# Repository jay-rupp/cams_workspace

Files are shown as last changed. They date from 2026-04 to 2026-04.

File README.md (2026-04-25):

# CAMS-Bot

**CArry My Stuff Bot** — a self-balancing two-wheeled follower robot designed as assistive technology for individuals with mobility impairments. CAMS-Bot autonomously follows a person and carries up to 5&nbsp;kg of cargo in residential environments.

Developed for **EECE 5552 – Assistive Robotics** at Northeastern University.

---

## Repository layout

| Path | Contents |
| --- | --- |
| `hardware/` | CAD files and hardware documentation for 3D-printed and laser-cut parts |
| `pico/` | MicroPython firmware for the Raspberry Pi Pico (real-time balance controller) |
| `src/` | ROS 2 workspace source — packages including `cams_bringup` |
| `dockerfile` | Container definition for the ROS 2 environment on the Pi 4 |
| `.gitignore` | |

---

## Hardware

- **Compute:** Raspberry Pi 4 (high-level control, ROS 2) + Raspberry Pi Pico (real-time balance loop)
- **Sensing:** OAK-D Pro camera (vision / person tracking), MPU6050 IMU (balance)
- **Actuation:** DFRobot FIT0186 12&nbsp;V DC gearmotors with quadrature encoders, L298N dual H-bridge driver
- **Wheels:** 8-inch polyurethane (Grainger 416P25)
- **Chassis:** Three+ laser-cut acrylic decks; 3D-printed PLA brackets and mounts; PETG wheel-to-motor bushings

---

## Setup

You will need:

1. **A Raspberry Pi 4** running Ubuntu with Docker installed.
2. **A Raspberry Pi Pico** flashed with the MicroPython UF2 firmware. Download the latest UF2 from the [official MicroPython site](https://micropython.org/download/RPI_PICO/) and flash it by holding the BOOTSEL button while plugging the Pico into USB, then dragging the UF2 onto the mounted drive.
3. **An Xbox controller** for teleop, paired to the Pi 4 over Bluetooth.

### 1. Clone the workspace

```bash
git clone <this-repo> ~/cams_workspace
cd ~/cams_workspace
```

### 2. Flash the Pico balance controller

Copy `pico/balance_controller.py` onto the Pico **as `main.py`** so it runs automatically on boot. The recommended workflow is VS Code with the [MicroPico](https://marketplace.visualstudio.com/items?itemName=paulober.pico-w-go) extension.

### 3. Build the Docker image

From the workspace root (where the `dockerfile` lives):

```bash
sudo docker build -t cams -f dockerfile .
```

### 4. Pair the Xbox controller

Pair the Xbox controller to the Pi 4 over Bluetooth before launching. Once paired, it will appear under `/dev/input/`.

```bash
bluetoothctl
# > scan on
# > pair <MAC>
# > trust <MAC>
# > connect <MAC>
```

---

## Running

### Launch the container

```bash
sudo docker run -it \
  --name ros-cams \
  --network host \
  --device /dev/ttyAMA3 \
  --device /dev/input \
  -v ~/cams_workspace:/workspace \
  cams
```

The flags do the following:

- `--network host` — required for ROS 2 DDS discovery
- `--device /dev/ttyAMA3` — UART link to the Pico
- `--device /dev/input` — exposes the Xbox controller to the container
- `-v ~/cams_workspace:/workspace` — mounts the ROS 2 workspace into the container

### Build and launch CAMS-Bot

Inside the container:

```bash
cd /workspace
colcon build
source install/setup.bash
ros2 launch cams_bringup cams_bot.launch.py
```

### Teleop controls

| Input | Action |
| --- | --- |
| Left stick Y | Forward / backward |
| Right stick X | Turning |

---

## Architecture

```
Xbox Controller ──BT──> Pi 4 ──ROS 2──> [joystick → cmd_vel → serial bridge]
                                                                 │
                                                          /dev/ttyAMA3
                                                                 │
                                                                 ▼
                                                              Pico
                                                          (MicroPython
                                                       balance controller:
                                                         IMU + encoders →
                                                          PID → L298N)
                                                                 │
                                                                 ▼
                                                          DC gearmotors
```

The Pi 4 handles high-level control and teleop; the Pico runs the real-time PID balance loop at ~20&nbsp;kHz PWM. Communication between them uses a USB serial protocol (`D<float>,T<float>\n` for drive/turn, `S\n` for stop).

---

## Authors

Built by Jason Rupp for EECE 5552. Vision and person-tracking pipeline maintained separately.

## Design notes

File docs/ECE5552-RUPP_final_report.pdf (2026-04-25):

# CAMS-Bot: A Self-Balancing Two-Wheeled Cargo Platform for Users with Mobility Limitations

Jason Rupp
Department of Electrical and Computer Engineering Northeastern University
Seattle, WA, USA
rupp.j@northeastern.edu

Abstract—Mobility-limited users in residential environments face a routine but high-leverage problem: transporting everyday items between rooms while their hands are needed for stability aids. Existing solutions either require the user to push the device or are sized and priced for industrial settings. This report describes CAMS-Bot, a residentially-scaled self-balancing two-wheeled cargo platform developed for the EECE 5552 Assistive Robotics course as a step toward closing this gap. The system is built around a Raspberry Pi 4 running ROS2 Jazzy in Docker for high-level control, a Raspberry Pi Pico running a cascaded PID balance controller in MicroPython at 100 Hz, an MPU6050 IMU, two 12 V DC gearmotors with quadrature encoders driving 8-inch polyurethane wheels through an L298N motor driver, and a hybrid chassis of laser-cut acrylic decks, 3D-printed PLA brackets, and PETG bushings at the wheel-motor coupling. Operator input is provided through an Xbox controller and a ROS2 teleoperation node communicating with the Pico over hardware UART. The delivered system balances reliably on residential carpet, accepts smooth teleoperated drive and turn commands, and holds the project’s headline 5 kg payload in static balance. Dynamic loaded locomotion at 5 kg fails for analyzed geometric reasons, and the originally proposed autonomous person-following capability was descoped during the project. The contribution is a working proof-of-concept platform with a fully documented controller, identified failure modes, and a concrete architectural roadmap to a deployable follow-on build.

I. INTRODUCTION
A. The assistive task and its users.

Many people who live with mobility limitations struggle to transport everyday items. For an impaired user, some transport tasks can be slow, painful, unsafe, or impossible without assistance. The assistive task addressed by this project was to build a small mobile robot that carries cargo on behalf of such a user and travels with them through a residential environment, freeing both of the user’s hands for stability aids and reducing the load they must support themselves.

B. Why the task matters.

Cargo carrying is a routine but high-leverage problem for the target population. Commercial service robots designed for cargo transport are sized and priced for warehouses and hospitals rather than apartments. A compact, low-cost, residentially scaled cargo robot that follows its user would meaningfully extend independent living, and the absence of such a device on the consumer market reflects the difficulty of building one well rather than a lack of need.

C. What makes the task technically challenging.
The technical challenge is unusually broad for a residential robot. The platform had to be small enough to maneuver around furniture, which pushed the design toward a two-wheel self-balancing form factor rather than a stable four-wheel base, and self-balancing introduces a real-time control problem on top of every other subsystem. The robot also had to carry a meaningful payload (the project targeted 5 kg, sufficient for the majority of personal cargo tasks), which interacts with the balance problem because added mass changes the chassis’s effective inertia and center of gravity. It needed to operate on common residential floor surfaces, such as carpet, hardwood, and tile, each of which presents different friction and rolling resistance that affect closed-loop stability. Finally, the long-term vision required onboard person tracking and following, which adds a perception pipeline running concurrently with a hard real-time balance loop on cost-constrained compute. Solving all of these problems simultaneously on a student budget was the core challenge of the project.
D. The system that was built.
CAMS-Bot (CArry My Stuff Bot) is a self-balancing two-wheeled cargo platform with a custom 3D-printed and laser-cut acrylic chassis, two 12 V DC gearmotors with quadrature encoders driving 8-inch polyurethane wheels through an L298N H-bridge, an MPU6050 IMU for tilt sensing, a Raspberry Pi 4 running ROS2 Jazzy for high-level control, and a Raspberry Pi Pico running a dual-loop PID balance controller. Drive commands are issued from an Xbox controller through a ROS2 teleoperation node on the Pi 4 and transmitted to the Pico over a hardware UART link. The system was originally scoped as follower bot with OAK-D Pro vision and YOLO-based person tracking. The delivered system balances reliably on carpet, accepts teleoperated drive, and successfully supports the 5 kg target payload during evaluation. The remainder of this report is organized as follows. Section 2 reviews related work. Section 3 describes the system as built. Section 4 presents the experimental evaluation, including PID tuning and load testing. Sections 5 and 6 discuss outcomes and lessons learned. Section 7 outlines limitations and future work.

II. RELATED WORK
CAMS-Bot sits at the intersection of three research areas: assistive mobile robotics for users with disabilities and mobility limitations, two-wheeled self-balancing platforms in the controls literature, and commercial autonomous cargo and human-following robots. This section reviews each area, identifies the gap CAMS-Bot targets, and positions the delivered system relative to prior work.
A. Target User and Context
The assistive function targeted by CAMS-Bot serves a large and well-documented population. The Centers for Disease Control and Prevention reports that disability affects a substantial fraction of the U.S. adult population, and mobility limitations are among the most common categories of disability [1]. National-level statistics on the use of mobility devices show that millions of Americans rely on these devices in daily life [2]. For this population, even routine in-home tasks that involve carrying objects compound an existing physical burden, as users must already manage a stability aid, a chronic condition, or both.
Within assistive robotics, the broad goal of empowering users with disabilities through robotic assistance is established in the literature. Chen et al. articulated this vision under the banner of ”robots for humanity,” demonstrating that mobile manipulation systems can extend independence for users with motor impairments [3]. More targeted work in the same space includes Balatti et al., who developed a robot-assisted navigation system for visually impaired users using adaptive impedance and path planning [4], and Deb et al., who designed and controlled an autonomous robot specifically for mobility-impaired patients [5]. Recent work by Olatunji et al. on the Stretch platform examines robotic support for older adults with combined cognitive and mobility impairments [6]. Common metrics for evaluating human-robot interaction in this space, including success rates, task completion times, and userreported workload, are reviewed by Steinfeld et al. [7] and operationalized through standard instruments such as NASA-TLX [8] and SUS variants [9].
CAMS-Bot’s contribution within this body of work is narrower than mobile manipulation or visual navigation. The platform addresses one specific assistive function, transporting cargo alongside a user, on a residentially-scaled chassis, leaving the user’s hands free for stability aids.
B. Existing Technical Approaches
Existing approaches relevant to CAMS-Bot fall into three categories: non-robotic mobility and carrying aids, commercial autonomous cargo and follower robots, and academic two-wheeled self-balancing platforms.
C. Non-robotic mobility aids.
Walkers, rollators, and wheeled shopping carts provide a small carrying surface for in-home and community cargo, but they require the user to push the device themselves. They provide no autonomy, no automatic following, and no mechanical assistance for the carrying task itself. For users whose strength does not support pushing a loaded device, or who need both hands free for a stability aid, these devices are inadequate.
D. Commercial autonomous cargo and follower robots. Commercial products in the human-following cargo category exist but are designed for industrial rather than residential contexts. The Foxtech FOLO-200, for example, is a four-wheel cargo robot rated for 100 kg payload and explicitly marketed for industrial transport and outdoor logistics [10]. Its scale, four-wheel base, and outdoor sensor stack are appropriate for warehouse and material-handling environments but not for the indoor residential use case CAMS-Bot targets, where the c hassis must navigate furniture and doorways. More broadly, commercial outdoor delivery robots have a documented record of safety problems in shared pedestrian environments. News reports from 2023 onward describe a sidewalk delivery robot that lost control and damaged residential property in East Hollywood [11], a delivery robot that repeatedly struck a man with cerebral palsy using a mobility scooter in West Hollywood [12], and a delivery robot that collided with an ambulance in Hollywood [13]. These incidents underscore that even well-funded commercial cargo robots do not yet operate safely around the very population that CAMS-Bot is intended to serve, and they motivate the design choice to keep the user as the direct operator of the platform rather than ceding control to a fully autonomous outdoor stack.
E. Academic and practical two-wheeled self-balancing robots. The two-wheeled self-balancing robot is a well-studied control problem, modeled as an inverted pendulum on a moving cart. PID, LQR, and hybrid control strategies have been evaluated extensively in the academic literature. Petcu and Andreescu compare PID and LQR controllers on a wheeled inverted pendulum and characterize the tradeoffs between the two approaches [14]. Saha et al. extend the platform with deep reinforcement learning alongside a PID baseline in their ”Epersist” framework [15]. Alongside the academic literature, practical builds in the maker community have demonstrated that competent balance is achievable with low-cost microcontroller hardware, an inexpensive MEMS IMU, encoderequipped DC gearmotors, and PID control. The CAMS-Bot balance controller is most directly informed by one such build: the widely-cited Instructables ”Arduino Based Self-Balancing Bot,” which provides a complete reference design including the cascaded PID structure (an inner tilt loop and an outer position or velocity loop), the MPU6050 IMU integration pattern, and a worked PID tuning sequence [16]. The CAMS-Bot implementation follows this template, with the following adaptations: the microcontroller is a Raspberry Pi Pico rather than an Arduino, the controller is written in MicroPython rather than the Arduino C dialect, the inner balance loop r uns at 100 Hz with the outer velocity loop running at a 10× lower rate via loop division, the motor driver is an L298N driven at approximately 20 kHz PWM, and the platform is scaled up to carry a 5 kg payload on 8-inch wheels rather than the small-form-factor demonstrator of the original build. Section 3.4 describes these adaptations and the dual-loop control architecture in detail.

III. SYSTEM DESIGN

A. Design Requirements

TABLE I
PROPOSAL REQUIREMENTS AND DELIVERY STATUS
Requirement | Status | Ref.

Functional
Carry payloads up to 5 kg while balanc- ing | Met | §4
Autonomously follow user at 0.5–1.5 m/s | Descoped | §3.4, §7
Maintain following distance of 0.5–1.0 m | Descoped | §3.4, §7
Detect and stop for obstacles in path | Descoped | §3.4, §7
No tracking device required on the user | Descoped | §3.4, §7

Usability
Manual override via gamepad controller | Met | §3.4
Fit through standard residential doorway | Met | §3.2

Safety
Cut motor output if tilt exceeds thresh- old | Partial | §3.4, §5
Stop on loss of user detection | Descoped | §3.4, §7
Cap autonomous following speed at 1.5 m/s | Descoped | §3.4, §7

The functional requirements are split between a delivered hardware-and-control layer and a descoped vision-andtracking layer. The 5 kg payload requirement, which was the headline assistive specification of the proposal, was satisfied during evaluation; the load test is described in Section
4. The remaining four functional requirements (autonomous following, distance keeping, obstacle response, and untethered tracking) all depend on the OAK-D Pro vision and DepthAI person-detection pipeline that was the responsibility of the project partner. That subsystem was not delivered, and consequently those requirements are reported as descoped rather than partial: no portion of the autonomous-following pipeline runs on the delivered system. The hardware required to support the descoped capability (the OAK-D Pro camera, its mount, and a wired connection to the Pi 4) is in place, and the Pi 4 to Pico command interface that an autonomous-following node would use is implemented and exercised by the manual-control node. Section 3.4 describes that interface, and Section 7 describes the work required to complete the autonomous-following capability. The usability requirements are met. The manual override mode operates through an Xbox controller connected to the Raspberry Pi 4, with commands forwarded to the Pico over hardware UART (Section 3.4). The chassis dimensions fit through a standard residential doorway. The safety requirements are partially met. The proposal’s first safety requirement specified an automatic motor cutoff if the tilt angle exceeds a safe threshold. As delivered, the system instead provides an operator-initiated kill switch that cuts power to the motors when pressed. This satisfies the requirement’s intent for the operator-in-the-loop case (the operator can disable the motors at any time), but it does not satisfy the original automatic-cutoff specification: a fall-class tilt event completes in well under a second, faster than an operator can be expected to react. An automatic tilt-threshold cutoff in the Pico balance loop is the natural extension and is identified as future work in Section 7. The remaining two safety requirements depend on the descoped vision subsystem. A stop-on-loss-of-detection behavior cannot exist without a detection pipeline, and a cap on autonomous following speed has no application when no autonomous mode is delivered. Both are reported as descoped rather than violated, since the conditions under which they would apply are not present in the delivered system. In the manual-control configuration, speed is governed by the operator and by the balance controller’s saturation behavior. A note on what is not in this table. The proposal did not separately list a requirement for stable balance across residential floor surfaces; balance was implicit in the functional requirements. As built, balance is reliable on carpet and adequate on smooth flooring such as hardwood and tile. This behavior is not a violation of any tabled requirement, but it is a real limitation of the delivered system and is discussed honestly in Section 4 (PID tuning) and Section 6 (lessons learned).
B. Robot Platform

CAMS-Bot is a self-balancing two-wheeled differentialdrive cargo platform. Figure 1 shows the assembled robot, and Figure 2 shows the system block diagram. The platform is built around four design choices that follow from the requirements in Section 3.1: a two-wheel inverted-pendulum form factor for residential maneuverability, 8-inch polyurethane wheels for traction on residential flooring, a split compute architecture that isolates real-time control from high-level processing, and a 12 V power bus sized for the motor and compute loads. Drivetrain. The drivetrain consists of two DFRobot FIT0186 12 V brushed DC gearmotors rated at 251 RPM, each with an integrated quadrature encoder. The motors are coupled to 8-inch polyurethane wheels through custom 3D-printed PETG hub adapters, described in Section 3.3. Polyurethane was selected for the wheel material because it provides higher friction on hardwood and tile than rubber-tread alternatives at the same wheel diameter, while remaining quiet on hard surfaces. The motors are driven by an L298N dual H-bridge motor driver. The L298N replaced an earlier TB6612FNG selection during integration after the TB6612FNG produced reliability problems under load; the L298N tolerated the stall and start-up currents of the 12 V gearmotors more robustly. Both motor channels are driven with PWM at approximately 20 kHz, which sits above the audible range and produces smoother current delivery to the motor inductance than lower switching frequencies.

Sensing. Tilt sensing for the balance loop is provided by an MPU6050 inertial measurement unit, which integrates a three-axis accelerometer and a three-axis gyroscope on a single I

2C device. The MPU6050 is mounted rigidly to the chassis with its sensitive axis aligned to the chassis pitch axis. Tilt angle is estimated by a complementary filter that fuses the gyroscope rate (good for short-term dynamics, prone to long-term drift) with the accelerometer-derived angle (good for long-term reference, sensitive to lateral acceleration noise). Wheel motion is sensed by the integrated quadrature encoders on each gearmotor; the Pico decodes the encoder edges in software to obtain wheel velocity for the outer velocity loop. Compute. The compute stack is split across two boards with deliberately separated responsibilities. A Raspberry Pi Pico runs the real-time balance control loop at 100 Hz. The Pico reads the IMU, decodes the encoders, runs the cascaded PID controller, and writes PWM commands to the L298N. A Raspberry Pi 4 hosts the high-level stack: Ubuntu, ROS2 Jazzy in Docker, the Xbox-controller joystick node, the teleoperation command publisher, and the serial bridge to the Pico. The two boards communicate over a hardware UART link using a simple ASCII protocol described in Section 3.4. Splitting the stack this way isolates the deterministic balance loop from the non-deterministic timing of Linux, ROS2, and any future perception pipeline.
Vision hardware. An OAK-D Pro depth camera is mounted at the top of the chassis on a custom 3D-printed mount. The camera connects to the Raspberry Pi 4 over USB. As discussed in Section 3.1, no vision software is integrated in the delivered system; the camera and its mount are present so that the planned DepthAI and YOLO-based person-tracking pipeline could be added without further mechanical or hardware work. User input and emergency stop. An Xbox controller is the user’s primary input device, connected to the Raspberry Pi 4 over bluetooth. Drive and turn commands are mapped from the controller’s analog sticks (left-stick Y for forward and back, right-stick X for turning) and forwarded over UART to the Pico. The platform also has a hardware kill switch that cuts power to the motors when pressed, providing the operator with an immediate physical override. The kill switch is the safety mechanism described in Section 3.1; an automatic tilt-threshold cutoff in the balance controller is identified as future work in Section 7.
Power. The platform uses a split power architecture. A 12 V DC battery feeds the L298N motor driver and supplies both motor channels. The Raspberry Pi 4 and the Raspberry Pi Pico are powered separately from a USB battery pack (Anker), which provides a regulated 5 V logic supply that is electrically isolated from the motor bus on the high side. The motor encoders are powered from the L298N’s onboard 5 V regulator output, so encoder logic levels are referenced to the motorside ground. Logic and motor grounds are tied together at a single point so that the Pico’s encoder inputs and PWM outputs share a common reference with the motor driver. Separating the logic and motor supplies in this way prevents motor inrush and stall currents from sagging the Pi 4’s rail and crashing the high-level stack, which is a known failure mode when both subsystems share a single battery.
Form factor. The chassis dimensions allow the robot to pass through a standard residential doorway. The cargo platform is integrated into the upper body of the chassis above the wheel axle and is sized to carry the 5 kg target payload.

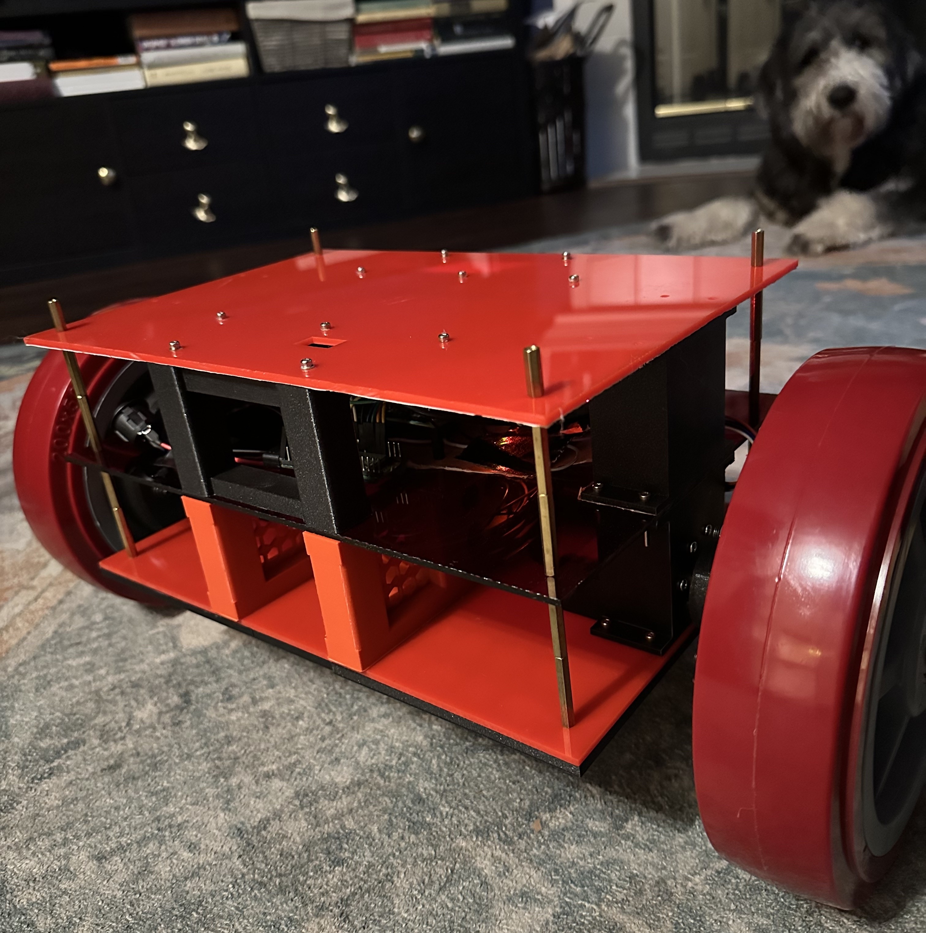
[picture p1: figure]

Fig. 1. CAMS-Bot, as built.

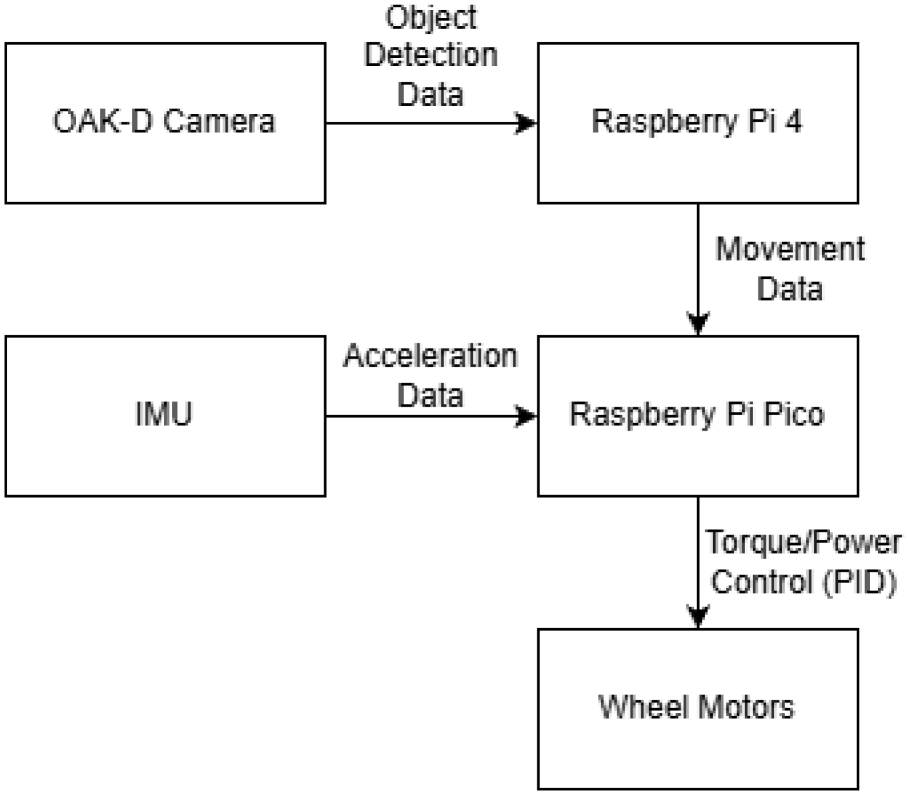
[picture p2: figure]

Fig. 2. System block diagram. The Pi 4 hosts ROS2 and the joystick teleoperation node; the Pico hosts the real-time balance and velocity loops. The OAK-D Pro and a vision-pipeline placeholder are shown for completeness; no vision software is integrated in the delivered system.

Every custom-fabricated part on the robot was designed in

CAD by the author and produced in-house at the Northeastern FlexLab maker space. The chassis is a hybrid build that uses three distinct fabrication processes and three materials, each chosen for the specific structural role it plays. Three or more laser-cut acrylic decks form the flat structural levels of the chassis; PLA-printed brackets and mounts attach the motors, battery, camera, and supports to those decks; and PETG-printed bushings couple the motor shafts to the wheels at the single highest-load mechanical interface on the robot. Twelve custom parts were designed and produced for the platform across these three categories. CAD files for all custom parts are included in the project repository.
Laser-cut acrylic decks. The chassis is built around three horizontal acrylic decks stacked vertically and joined by metal standoffs. The decks carry the electronics (motor driver, Pico, wiring, battery) on the lower levels and the cargo platform on the upper level. Acrylic was selected for the decks because the deck geometry is essentially two-dimensional: large flat panels with regular hole patterns for component mounting and standoff connections. Laser cutting produces this geometry in a single pass with tight tolerances and smooth edges, and acrylic is dimensionally stable enough that the standoff hole patterns line up reliably across all decks for clean stacking. PLA-printed brackets and mounts. The bracketry that attaches components to the acrylic decks is 3D-printed in PLA. This includes the FIT0186 motor mounts, the OAK-D Pro camera mount, the Anker battery holder for the logic-side power pack, the 12 V motor battery holder, and the structural supports that brace the deck stack against bending. PLA was the default printer feedstock available in the FlexLab and was the right choice for these parts: the brackets carry static or low-cycle loads (holding components in place against gravity and occasional handling) rather t han the repeated high-cycle loads at the wheel-motor interface, and PLA’s stiffness and dimensional accuracy serve the mounting role well. PETG-printed wheel bushings. The single highest mechanical demand on the robot is the wheel hub bushing, which couples each motor’s flatted D-shaft to the round bore of the 8-inch polyurethane wheel. Every newton-meter of motor torque is transmitted through this part, and it sees repeated impact loads from the wheel-ground contact during balancing, driving, and disturbance recovery. The bushings (Bush_v2.stl) were therefore printed in PETG rather than PLA, because PETG offers materially better toughness and creep resistance under cyclic and impact loading than PLA. PETG was scarce in the FlexLab inventory and was obtained for these parts by request to the lab staff; reserving it for the bushings, where its mechanical advantage actually matters, was a deliberate allocation given the limited supply. The bushings were also the most-iterated mechanical part on the robot. Several print revisions were required to converge on a fit that gripped the motor’s flatted shaft tightly enough not to slip under torque, while remaining loose enough to install and remove without damaging the wheel.
Design rationale and fabrication constraints. The hybrid construction reflects a deliberate match between fabrication processes and the loads each part carries: laser-cut acrylic for flat structural geometry, 3D-printed PLA for shaped lowload bracketry, and 3D-printed PETG only at the single mechanical interface where its toughness was needed. The chassis dimensions were further constrained by the working envelopes of the available equipment in the FlexLab: the laser cutter’s bed sets an upper bound on deck dimensions, and the 3D printer’s build volume sets an upper bound on the size of any single printed part. The latter constraint forced several mechanical functions to be split across multiple printed parts rather than designed as unified brackets. Producing all custom parts in-house from CAD also kept iteration cost low.

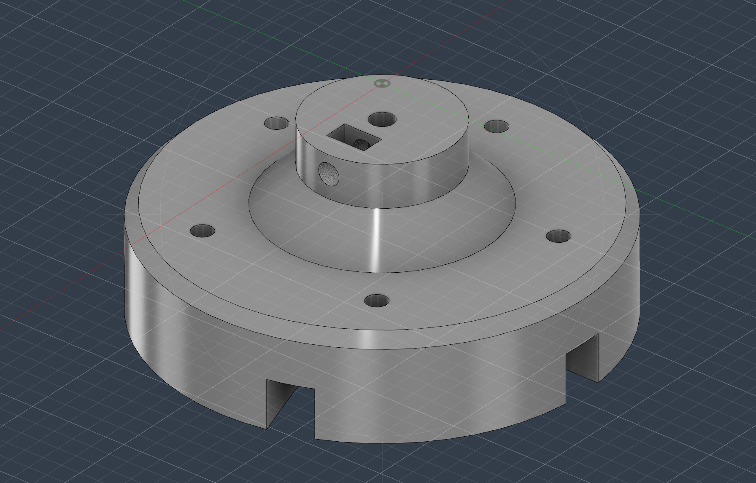
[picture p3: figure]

Fig. 3. CAD render of the PETG-printed wheel bushing (Bush_v2.stl), which couples the FIT0186 motor’s flatted D-shaft to the 8-inch polyurethane wheel. This is the single highest-load custom part on the robot.

C. Software Architecture

The CAMS-Bot software stack is split across the two compute boards described in Section 3.2, with the split chosen to isolate the deterministic real-time balance loop from the non-deterministic timing of Linux, ROS2, and any future perception pipeline. Figure 4 shows the block diagram of the delivered stack. The Raspberry Pi 4 hosts the high-level layer (Ubuntu, ROS2 Jazzy in Docker, the joystick teleoperation node, and the serial bridge to the Pico). The Raspberry Pi Pico hosts the low-level layer (the MicroPython balance controller, encoder decoding, and the L298N motor driver interface). The two boards communicate over a hardware UART link with a small ASCII protocol described below.
High-level layer (Raspberry Pi 4). The Pi 4 runs Ubuntu with ROS2 Jazzy hosted inside a Docker container. Containerizing the ROS2 environment isolates the project’s dependencies from the host system and makes the high-level stack reproducible: the same Docker image can be rebuilt on a fresh Pi 4 image with no manual ROS2 installation. Two ROS2 nodes are deployed in the container. The joystick node reads input from an Xbox controller connected over USB using pygame and publishes the controller state to the standard ROS2 /joy topic. The teleoperation node subscribes to /joy, maps the controller’s left-stick Y axis to a normalized

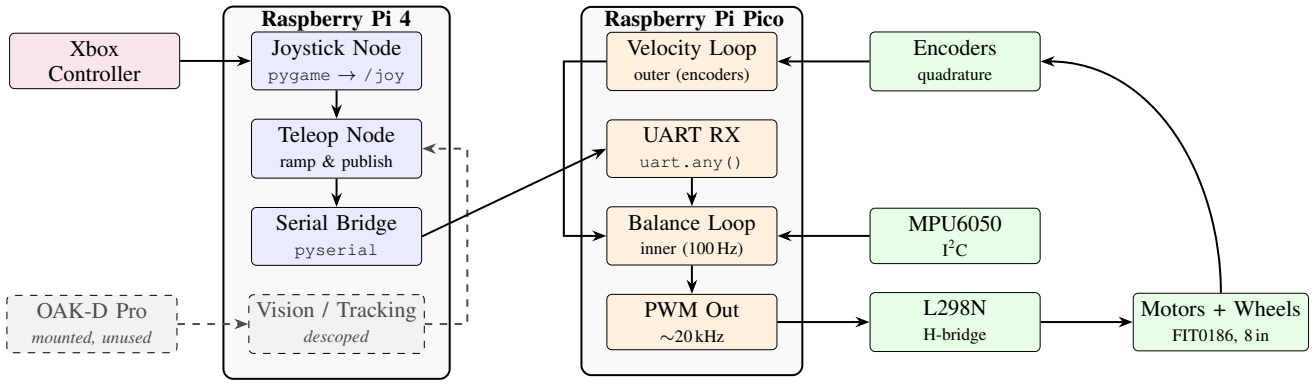
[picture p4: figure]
Raspberry Pi 4; Raspberry Pi Pico; Joystick Node; pygame → /joy; Teleop Node; ramp & publish; Serial Bridge; pyserial; Vision / Tracking; descoped; UART RX; uart.any(); Velocity Loop; outer (encoders); Balance Loop; inner (100 Hz); PWM Out; ∼20 kHz; Encoders; quadrature; MPU6050; H-bridge; Motors + Wheels; FIT0186, 8 in; Xbox Controller; OAK-D Pro; mounted, unused

Fig. 4. Software architecture and signal flow. The Raspberry Pi 4 (left, blue) runs ROS2 Jazzy in Docker with a joystick node, a teleoperation node, and a serial bridge. The Raspberry Pi Pico (center, orange) runs the cascaded PID controller in MicroPython: an outer velocity loop biases the inner balance loop’s tilt setpoint, and the inner loop drives the L298N motor driver at ∼20 kHz PWM. Hardware peripherals are shown in green. The OAK-D Pro camera and vision/tracking node (dashed) are physically present but were descoped from the delivered system.

drive command and the right-stick X axis to a normalized
turn command, ramps the commanded values at 20 Hz inside
a timer callback to avoid step changes that would shock the balance loop, and writes the resulting commands to the Pico over a serial port using pyserial.
The serial port is exposed as a stable symlink /dev/ttyPICO via a udev rule keyed on the Pico’s USB vendor ID (2e8a). This rule guarantees that the device path does not change across reboots or USB re-enumerations, which removes a class of bugs where the teleoperation node would attach to the wrong device after a hot-plug. Low-level layer (Raspberry Pi Pico). The Pico runs the real-time balance controller in MicroPython at a 100 Hz inner-loop rate. On each loop iteration the Pico (i) reads the MPU6050 IMU over I²C, (ii) estimates the chassis tilt angle from the accelerometer and gyroscope using a complementary filter, (iii) reads the wheel encoders to estimate wheel velocity, (iv) runs the cascaded PID controller described in the next paragraph, and (v) writes PWM commands to the L298N motor driver. The PWM frequency to the L298N is approximately 20 kHz, which sits above the audible range and produces smoother current delivery to the gearmotor inductance than lower switching frequencies.
Control: cascaded PID architecture. Balance and motion are produced by a cascaded two-loop controller. The inner balance loop runs every control tick and regulates chassis tilt: it produces a motor PWM command from the tilt error (measured tilt minus commanded tilt setpoint) and the tilt rate, through a PID controller with proportional, derivative, and small integral terms. The derivative term is filtered through an exponential moving average to suppress gyroscope noise, and the integral term is clamped to prevent windup during disturbances. The outer velocity loop runs at a lower rate, divided down from the inner-loop rate by an integer factor (VEL_LOOP_DIV). It compares the wheel-velocity estimate from the encoders against the commanded drive value from the high-level layer and slowly biases the inner loop’s tilt setpoint accordingly. This is the mechanism by which the robot translates a “drive forward” command into actual motion: the velocity loop deliberately leans the chassis in the desired direction, and the balance loop drives the wheels to keep up. A separate turn channel adds and subtracts a differential PWM bias to the two motor commands to produce yaw motion. The specific gain values and tuning history are reported in Section 4.
User interface. The user interface is a wired Xbox controller connected to the Pi 4 over USB. The left stick Y axis controls forward and reverse drive; the right stick X axis controls turning. Drive and turn inputs are normalized to the range [−1, 1] on the Pi 4 side and transmitted to the Pico in the ASCII protocol described next. A graphical or voice interface was not in scope.
Communication: Pi 4 to Pico ASCII protocol. The two boards communicate over a hardware UART link with a deliberately simple line-oriented ASCII protocol. Drive and turn commands are sent as D<float>,T<float>\n, where D is the normalized drive value and T is the normalized turn value, both in [−1, 1]. An immediate stop is sent as S\n. The Pico’s UART receive uses uart.any() to check for available bytes before reading, which gives a non-blocking read pattern compatible with the 100 Hz control loop. An earlier design used USB CDC serial on the Pico’s USB device interface; this was abandoned after persistent blocking-read failures, in which readline() would block on incoming newlines, read(n) would block on byte counts, and even single-byte buffered reads were sufficient to break the control loop’s timing budget. Switching to hardware UART with uart.any()-gated reads resolved the problem cleanly. Perception (descoped). The system architecture diagram shows a dashed perception module corresponding to the OAK-D Pro depth camera and the originally planned DepthAI and YOLO-based person-tracking pipeline. As discussed in Section 3.1, this subsystem was not delivered. The camera is physically mounted on the chassis and connected over USB to the Pi 4, but no vision software is integrated, no perception nodes are present in the ROS2 graph, and no autonomous mode runs on the Pi 4. The architecture is built so that adding the perception module would not require changes to the high-level node graph beyond inserting the node itself: the teleoperation node’s command interface (the same drive and turn channel forwarded over UART) is the natural insertion point for autonomous commands.
Planning (descoped). No planner runs on the delivered system. The proposed autonomous-following behavior would have used the perception module’s person-position estimate to compute drive and turn commands directly, without a separate planning layer; that simple control law was the planning equivalent in the original design and would attach at the same insertion point as the perception module above. Freespace planning, obstacle-avoidance planning, and map-based navigation were never in scope.
Safety. The delivered safety mechanism is a hardware kill switch that cuts power to the motors when pressed, providing the operator with an immediate physical override. As discussed in Section 3.1, this satisfies the operator-in- the-loop case but does not satisfy the proposal’s automatic-tilt-cutoff requirement, since fall-class tilt events complete in well under a second. An automatic tilt-threshold cutoff in the Pico balance loop is identified as future work in Section 7.
Changes from the proposal. Five elements of the software architecture changed between the proposal and the delivered system. (1) The motor driver was changed from the TB6612FNG specified in the proposal to the L298N, after the TB6612FNG produced reliability problems under the load conditions of the 12 V gearmotors. (2) The Pico balance controller is implemented in MicroPython rather than the C++ originally specified, because MicroPython provided a faster iteration loop on the Pico for the tuning-heavy development style the project required. (3) The inner balance loop runs at 100 Hz rather than the 200 Hz specified in the proposal; 100 Hz proved sufficient for stable balance and was the rate at which the IMU read, encoder decode, and PID computation comfortably fit within the loop period. (4) The Pi 4 to Pico link is hardware UART rather than USB CDC, after the USB CDC implementation was found to introduce blocking-read behavior incompatible with the control loop’s timing budget.
(5) The autonomous-following capability based on the OAK-D Pro and DepthAI was descoped, as discussed at length elsewhere in this report. The first four changes are technical refinements that produced a more reliable delivered system; the fifth is a scope reduction that resulted from the project partner’s withdrawal from the course.

IV. EXPERIMENTAL EVALUATION

A. System Tasks
The CAMS-Bot proposal defined the primary assistive task as autonomously following a user while carrying a load in a residential environment, decomposed into five subtasks: person detection and acquisition, person following, load carrying under balance, obstacle response, and manual override. As discussed in Section 3, four of these five subtasks (all but load carrying and manual override) depend on the OAK-D Pro vision and DepthAI person-tracking pipeline, which was descoped from the delivered system. Evaluating the delivered system against the original five-subtask decomposition would consist mostly of reporting “not delivered” for vision-dependent rows, which is uninformative.
This section instead evaluates the delivered system against the subset of tasks that the as-built hardware and software actually perform. Three tasks are evaluated: dynamic balance, teleoperated drive and turn, and load carrying under balance. These three tasks together exercise the full delivered stack, from the Xbox controller through the Pi 4 teleoperation node, the UART link, the Pico cascaded PID controller, and the L298N motor driver to the wheels and the chassis. They are also the three tasks against which the headline assistive specification of the project (the 5 kg payload requirement) is meaningful: a balanced platform that accepts manual drive commands and holds 5 kg of cargo is what the delivered system is, and is the closest defensible approximation of the proposal’s load-carrying-under-balance subtask.
Task 1: Dynamic balance. The robot must maintain its upright pose against the natural disturbances of the chassis and surface (small irregularities in the floor, residual asymmetries between the two motor channels, wiring tug, and so on) for an extended period without operator command. This task tests the inner balance loop in isolation and is the first task the controller had to perform during PID tuning.
Task 2: Teleoperated drive and turn. The robot must respond to drive and turn commands issued from the Xbox controller through the ROS2 teleoperation node, translating those commands into forward and reverse motion and yaw rotation while continuing to balance. This task exercises both the high-level stack (joystick node, teleoperation node, UART serial bridge) and the cascaded PID controller (the outer velocity loop that biases the inner loop’s setpoint to produce drive motion, and the differential-PWM mechanism that produces yaw motion).
Task 3: Static load-bearing and loaded locomotion. The robot must perform Tasks 1 and 2 while carrying a payload on the cargo platform, up to the project’s headline 5 kg target. This task is the assistive specification of the project: a balance platform that cannot carry meaningful cargo is not useful for the assistive task in Section 1. Task 3 is decomposed into two distinct subcases, because the delivered system’s behavior differs sharply between them. The static subcase (Task 3a) requires the robot to hold the upright pose with 5 kg of cargo on the platform, without commanded motion. The dynamic subcase (Task 3b) requires the robot to perform the drive and turn behaviors of Task 2 while loaded with 5 kg. As detailed in Section 4.4, the delivered system passes Task 3a and fails Task 3b, and the failure mechanism is geometric rather than control-related: the cargo platform sits above the wheel axle, and on the current 8-inch wheels the lean required to initiate motion under the velocity loop swings the cargo’s center of mass past the contact patch before the controller can translate

the chassis forward.
The vision-dependent tasks from the proposal (person detection and acquisition, person following, and obstacle response) are not evaluated. The proposal’s metrics for these tasks (following success rate, following distance error, and obstacle stop distance) are reported as not-applicable in Section 4.4 rather than reported with degenerate values, since the conditions of measurement (an autonomous mode, a tracked user, and a perception-driven obstacle response) are not present in the delivered system.
B. Metrics

The proposal defined five quantitative metrics for system evaluation: following success rate, following distance error, balance stability under load, obstacle stop distance, and override response time. Three of the five (following success rate, following distance error, and obstacle stop distance) measure the autonomous-following behaviors that depend on the descoped vision pipeline and are not applicable to the delivered system. Section 4.4 reports those rows as “not applicable” rather than zero, since their conditions of measurement (an autonomous mode, a tracked user, and a perception-driven obstacle response) are not present in the delivered system. The remaining two proposal metrics, balance stability under load and override response time, apply to the delivered system but in modified form. The proposal’s balance stability metric specified zero falls per trial across three payload levels (0 kg, 2.5 kg, and 5 kg), with each trial consisting of a 10 m walked path. The delivered system was tested at the binary endpoints of this payload range (unloaded driving and static 5 kg balance) rather than across the swept payload sweep the proposal specified, for the reasons discussed in Section 4.1 and Section 4.5. The override response metric (time from controller input to motor stop) applies directly to the delivered system, since both the hardware kill switch and the S serial stop command produce an immediate motor cutoff observable to the operator.
The metrics applied in this evaluation are organized by the three tasks defined in Section 4.1.
Task 1: Dynamic balance.
- Static stability outcome. Whether the unloaded chassis maintains upright pose without operator command for the duration of a test trial. Reported as a pass/fail outcome from video evidence.
- Surface dependence. Qualitative comparison of stability on residential carpet versus smooth flooring (hardwood and tile). Reported as observed behavior.
- Tuning convergence. The PID gain values that produced acceptable balance behavior, including the proportional gain KP , the integral gain KI , the derivative gain KD, the tilt setpoint, the deadband, and the minimum effective PWM. Reported as the final tuned configuration.
Task 2: Teleoperated drive and turn.
- Command responsiveness. The qualitative responsiveness of the chassis to drive and turn commands from the Xbox controller, including any observed latency or non-linearity between input and motion. Reported from video evidence.
- Override response. The behavior of the kill switch and the S serial stop command. Reported as observed cutoff behavior.
Task 3a: Static load-bearing.
- Static load capacity. The maximum payload the chassis and balance controller hold in static upright pose without falling. Reported as the binary outcome of the static 5 kg test (pass/fail).
Task 3b: Loaded locomotion.
- Dynamic load capacity. Whether the chassis can perform Task 2 (drive and turn) while loaded with 5 kg. Reported as the binary outcome of the loaded-driving test (pass/fail).
A note on quantitative versus qualitative reporting. The metrics defined here are largely qualitative or binary, rather than the continuous quantitative measures the proposal specified. This reflects two practical realities of the delivered evaluation. First, the descoped autonomous mode removes the only context in which several of the proposal’s continuous metrics (following distance error, obstacle stop distance, following success rate over many trials) would have been meaningful. Second, the project’s instrumentation and timeline did not include logged tilt-angle traces, encoder-velocity traces, or other continuous signals that would have permitted RMSerror or bandwidth reporting of the kind that fully quantifies a balance controller. The value of automated logging for future builds of this kind of system is revisited in Section 5 (Lessons Learned).
C. Experimental Procedure
The experimental work on CAMS-Bot was hand-tuning of the cascaded PID balance controller, followed by integration testing of the teleoperation stack and the load test. This section documents the procedure in enough detail for reproducibility on a similar build.
Setup conditions. Tuning was conducted indoors on residential carpet, which is the surface on which the controller behaves most reliably (Section 4.4). The robot was powered from the split power architecture described in Section 3.2 (12 V battery for the motors, USB battery pack for the Pi 4 and Pico). The Xbox controller was paired to the Pi 4 by USB. The MicroPython balance controller was edited and flashed using the MicroPico extension in VSCode, and a serial monitor on the same workstation provided real-time access to the Pico’s print output during tuning. A toggle bound to the keypress p over the serial monitor enabled the Pico to print the tilt angle and gyroscope rate at 10 Hz while balancing, which was the primary diagnostic signal during gain selection.
Pre-tuning checks. Before any controller gain was set, three pre-conditions were verified on each session, because each had been the cause of an earlier debugging session that wasted time and is documented here so that future builds do not repeat them. (i) The MPU6050 boot sequence was given a

2 s startup delay in software before the first I²C read, since shorter delays produced intermittent boot failures of the IMU. (ii) The IMU sign convention was verified empirically by tilting the chassis forward by hand and confirming the sign of the reported angle (forward tilt produces a negative value in the firmware’s convention), since a sign error in the IMU reading inverts the controller and produces an immediate fall. (iii) A motor-deadband feedforward was added to compensate for the gearmotors’ nonzero electrical start threshold. The DFRobot FIT0186 gearmotors do not begin to rotate below approximately 1 V at the motor terminals, so PWM commands below this threshold produce no motion regardless of polarity, and the closed loop is effectively open in that range. Rather than apply a simple floor (which an earlier version of the firmware tried, and which produced visible oscillation at the deadband boundary because of the discontinuous PWM step), the delivered firmware holds the motor fully off below an absolute PID output of MIN_CMD = 100 and linearly ramps a feedforward offset from zero up to MOTOR_OFFSET = 30000 between MIN_CMD and TRANSITION = 2800, with sign preserved. This produces a smooth zero-crossing at the motor’s start threshold and ensures that any controller correction the loop wants to issue is actually executed.
Tuning sequence. The PID tuning proceeded in the following order, which is the order recommended by the Instructables reference build [16] and is the order that converged in practice:
1) KP alone (pure-P loop). With KI = KD = 0, KP was increased from a small value upward until the controller produced a visible corrective response when the chassis was deflected by hand. The diagnostic for “KP is in the right neighborhood” is that the chassis fights small disturbances and tries to return to vertical, but overshoots in the form of low-frequency oscillation around the upright pose. A trial with this configuration ends when the chassis falls, when the operator stops the trial via the kill switch, or when the chassis settles into oscillation. This step also doubled as a sanity check on the IMU sign convention and the motor wiring polarity: a controller that drives the chassis further from vertical when deflected is sign-inverted somewhere, and was caught at this step rather than later.
2) Add KD. With KP fixed near its single-gain limit, KD was increased from zero until the low-frequency oscillation from Step 1 was visibly damped. The diagnostic for “KD is in the right neighborhood” is that small hand-applied disturbances are caught early in the tilt and corrected smoothly, rather than letting the tilt grow into the regime where KP produces an aggressive correction. The derivative term was filtered through an exponential moving average on the tilt rate, because raw gyroscope noise without filtering produced high-frequency motor chatter at large KD values. A trial at this step ends on a fall, a kill-switch stop, or an extended period of quiet upright balance.
3) Adjust the tilt setpoint. A persistent slow drift in one direction during otherwise quiet balance is a sign that the commanded tilt setpoint does not match the chassis’s physical balance point. The setpoint was adjusted by small increments (on the order of 0.1 deg) until the drift disappeared. The setpoint was tuned before KI rather than relying on KI to correct the steady-state offset, because integral action on a wrong setpoint produces windup rather than convergence.
4) Add KI (small). With the setpoint correctly placed, KI was increased from zero in small steps. The integral term was clamped to a finite range to prevent windup during disturbances, and was zeroed when the controller entered the deadband (defined below). For most of the development cycle KI remained at zero, since the correctly-placed setpoint plus the P and D terms produced acceptable steady-state behavior; the integral gain was used only when a small persistent offset reappeared after mechanical changes to the chassis (the addition of the camera mount, for example, shifted the balance point by enough to require either a setpoint retune or a small integral correction).
5) Engage the velocity loop. With the inner balance loop stable, the outer velocity loop was engaged. The velocity loop reads wheel velocity from the encoders, compares it against the commanded drive value from the Pi 4, and biases the inner loop’s tilt setpoint accordingly. The velocity-loop divisor (VEL_LOOP_DIV) was set so that the velocity loop runs at one-tenth the inner-loop rate, since a velocity loop that runs as fast as the balance loop produces inner-outer interaction (the velocity loop reacts to the balance loop’s transients) rather than treating the inner loop as a settled plant. Velocity-loop gains were small relative to the balance-loop gains, since their job is to bias rather than dominate the setpoint.

Deadband behavior. A small deadband was applied around the tilt setpoint inside which the controller output was zero, to prevent the controller from chattering the motors against the natural noise floor of the IMU and the encoders while the chassis was already approximately upright. A subtle bug surfaced during tuning and is documented here: the deadband must not reset the previous-error and filtered-derivative state to zero on entry. Resetting those values caused a derivative spike on each deadband re-entry, which produced visible motor twitches at the deadband boundary and degraded overall balance. The corrected behavior preserves prev_error and filtered_d across deadband transitions; the deadband only zeroes the output, not the controller’s internal state.
Trial structure. A balance trial began with the operator holding the chassis upright by hand, releasing it once the controller appeared to engage, and observing the chassis behavior until one of three terminating conditions was reached:
- Fall: the chassis tilted past the operator’s recoverable angle (approximately 30◦
from vertical) and was caught by hand or by the floor. The kill switch was used in this case to cut motor power before contact with the floor

when possible.
- Operator stop: the operator pressed the kill switch in response to oscillation, drift, or any unsafe behavior, ending the trial without a fall.
- Success: the chassis maintained upright pose, with motion confined to small natural disturbances of the surface and the wiring, for a duration sufficient to demonstrate stable balance.
A new trial began either by editing the controller gains in the firmware and re-flashing the Pico (for tuning iterations), or by simply restarting the controller with the same gains (for repeat trials of a converged configuration).
Teleoperation and load tests. Once the balance controller was tuned, the Xbox controller and the ROS2 teleoperation node were brought up on the Pi 4, and Task 2 (drive and turn) was tested by issuing drive and turn commands while the chassis balanced. The load tests for Task 3 used a known mass placed on the cargo platform: a successful Task 3a trial held the chassis upright with the 5 kg payload for the duration of a video-recorded clip; a Task 3b trial issued small drive commands under the loaded condition and was terminated by the resulting fall (Section 4.4).
Reproducibility. The MicroPython firmware, the ROS2 nodes, the udev rule for /dev/ttyPICO, and the CAD files for all custom hardware are included in the project repository. With access to the same hardware bill of materials, a reasonable-fidelity reproduction of the delivered system should be achievable in a single semester. The hard-won lessons that saved the most debugging time, listed in priority order, are:
(i) set MIN_PWM above the motor’s electrical start threshold; (ii) delay the first IMU read by 2 s after Pico boot; (iii) filter the derivative term and clamp the integral term; (iv) preserve controller state across deadband transitions; and (v) tune the setpoint before introducing KI . These items are revisited as recommendations for future teams in Section 5.
D. Results
Table II reports the outcomes of the metrics defined in Section 4.2, organized by the three tasks from Section 4.1. Quantitative values are reported where they were measured; qualitative or binary outcomes are reported where the metric was qualitative or binary by design. The remainder of the section expands on the entries that require more than a one-cell summary.
Tuning convergence (Task 1). The PID tuning sequence described in Section 4.3 converged to the gain set reported in Table III. These are the values that were live in the firmware during the video-documented balance and load tests, and constitute the controller configuration that produced the Task 1 and Task 3a passes.
Surface dependence (Task 1). The controller is tuned for, and behaves most reliably on, residential carpet. On smooth flooring such as hardwood and tile the same controller produces visibly less stable behavior: small disturbances that the carpet case rejects without operator intervention can grow on smooth flooring into oscillations large enough to require

TABLE II
RESULTS BY TASK AND METRIC
Metric | Outcome

Task 1: Dynamic balance
Static stability outcome | Pass on carpet
Surface dependence | Reliable on carpet; degraded on hardwood/tile
Tuning convergence | Final gains in Table III

Task 2: Teleoperated drive and turn
Command responsiveness | Pass; smooth response to drive and turn
Override response | Pass; immediate motor cutoff on kill switch and S stop

Task 3a: Static load-bearing
Static load capacity | Pass at 5 kg

Task 3b: Loaded locomotion
Dynamic load capacity | Fail at 5 kg (geometric tipping; see below)

Descoped (vision-dependent)
Following success rate | Not applicable
Following distance error | Not applicable
Obstacle stop distance | Not applicable

a kill-switch stop. Two contributing causes are likely. First, carpet adds rolling resistance that passively damps small velocity excursions before the velocity loop reacts to them, while smooth flooring offers no such damping. Second, the 8-inch polyurethane wheels selected for the project are intended for smooth warehouse-style floors at much higher loads than this robot applies; their durometer and tread profile produce a small, hard contact patch on smooth flooring that gives the controller less margin than a softer or larger wheel would. The combination of the as-built wheels and the controller’s lack of any surface-adaptive behavior produces the carpet-versussmooth-floor asymmetry observed during testing.
Command responsiveness and override (Task 2). The teleoperated drive and turn behaviors performed as designed. Drive commands from the Xbox controller’s left-stick Y axis produce smooth forward and reverse motion on the chassis, with the velocity loop biasing the inner loop’s tilt setpoint to lean the chassis in the commanded direction. Turn commands from the right-stick X axis produce yaw rotation through the differential-PWM mechanism. There is no observable latency between controller input and chassis response beyond what the 20 Hz teleoperation publish rate and the 100 Hz inner loop together permit. The override response is immediate by construction: the hardware kill switch cuts power to the motors at the electrical level, and the S serial stop command is executed by the Pico on the next inner-loop iteration after the byte arrives over UART, both of which produce a motor cutoff faster than an operator can perceive a delay.
Static load-bearing at 5 kg (Task 3a). The chassis, decks, motor mounts, wheel bushings, and balance controller hold the bot upright with 5 kg of cargo on the platform. The controller’s

TABLE III
FINAL TUNED CONTROLLER CONFIGURATION
Parameter | Value | Notes

Inner balance loop (PID)
KP | 1000.0 | Proportional gain
KI | 0.0 | Disabled; | infrastructure
| | clamped
KD | 700.0 | EMA-filtered
(D_FILTER_ALPHA=0.3)
Tilt setpoint | −1.0
- Empirical balance point
Deadband | 0.3
- State-preserving
Integral zone | 2.0
- Engages KI inside this band
Integral clamp | ±8.0 | Anti-windup limit

Outer velocity loop (PID)
VEL_KP | 0.002 | Velocity proportional
VEL_KI | 0.0006 | Velocity integral
VEL_KD | 0.0 | Disabled
VEL_LOOP_DIV | 10 | Outer/inner rate ratio
VEL_INTEGRAL_CLAMP | ±1.5 | Anti-windup limit
VEL_MAX_OFFSET | ±2.0
- Max setpoint bias
VEL_D_FILTER | 0.08 | Derivative low-pass

Drive input shaping
MAX_DRIVE_ANGLE | 1.5
- Lean at full stick
VEL_DRIVE_SCALE | 5500 | Trigger → velocity target
TURN_SCALE | 10000 | Stick → turn differential
VEL_RAMP_RATE | 4000 | Velocity target slew
DRIVE_RAMP_RATE | 8.0 | Drive target slew
TRIGGER_EDGE | 0.2 | Stick deadzone

Stiction-overcome kick
KICK_PWM | 12000 | Initial pulse from rest
KICK_DECAY | 0.88 | Per-tick decay factor
KICK_MIN | 200 | Floor before kick disengages

Output conditioning
MAX_OUTPUT | 65535 | 16-bit Pico PWM full scale
MIN_CMD | 100 | Below this |u|, motor fully off
MOTOR_OFFSET | 30000 | Deadband feedforward (full)
TRANSITION | 2800 | PID output where offset is
fully active
Output filter α | 0.3 | EMA on commanded output

IMU fusion and rates
Complementary α | 0.98 | Gyro | vs. | accelerometer
| | weight
Inner-loop rate | 100 Hz | MicroPython on Pico
PWM frequency | ∼20 kHz | L298N drive

existing gains (Table III), tuned for the unloaded chassis, are sufficient to maintain static balance under the increased mass and the raised center of gravity. This passes the project’s headline assistive specification on the static portion of the loadcarrying task.
Loaded locomotion failure (Task 3b). The 5 kg loaded locomotion case fails. The mechanism, summarized in Section 4.1 and analyzed in Section 4.5, is geometric: the cargo platform sits above the wheel axle, and on the current 8-inch wheels even a small commanded lean swings the cargo’s center of mass past the wheel’s contact patch before the velocity loop can deliver enough wheel acceleration to translate the chassis forward. Once the cargo center of mass crosses the contact patch, gravity’s moment arm exceeds what the motors can counter and the chassis tips. This failure is not addressable by gain tuning, since the lean that produces the failure is the same lean the velocity loop commands to initiate motion. Section 7 (Future Work) identifies larger-diameter wheels (in the range of 24–29 inches) and a chassis redesign that places the cargo platform closer to or below the wheel axle as the architectural changes that would address the failure.
Tuning headroom. The gain set in Table III produced acceptable balance behavior across the test trials but does not represent a maximally tight tuning. Two further refinements are visible from the test behavior. First, the controller is non-adaptive: the same gain set is applied across all surface conditions and all loaded conditions, and the surface-dependence asymmetry above and the loaded-locomotion failure each arise in part from the absence of a plant-conditioned gain schedule. A gain-scheduled controller, or an autotuning mechanism that adjusts gains in response to measured plant response, would address both. Second, the inner-loop gains were tuned by hand against visible chassis behavior rather than against a logged tilt trace; a logging-driven retune would tighten the gains by allowing overshoot, settling time, and steady-state error to be measured quantitatively rather than estimated visually. These refinements are identified as future work in Section 7.
E. Analysis and Discussion
Performance against requirements. The delivered system meets the proposal’s headline static specification (carrying 5 kg) and meets the operator-control and override requirements, but falls short of the dynamic 5 kg specification and of the autonomous-following functional set. The proposal’s payload requirement was articulated as “carry payloads up to 5 kg while maintaining balance,” which on a literal reading the static load test (Section 4.4, Task 3a) satisfies. On a more demanding reading, in which “carry” implies locomotion, the dynamic load test (Task 3b) does not satisfy the requirement. The honest verdict is partial: the structural and balance work that the static 5 kg case demands is delivered, and the architectural work the dynamic 5 kg case demands is not. The autonomous-following functional requirements (following at 0.5–1.5 m/s, distance keeping, obstacle response, untethered tracking) were descoped with the withdrawal of the project partner responsible for the vision pipeline, and the safety requirements that depend on those autonomous behaviors (stop on loss of detection, autonomous-mode speed cap) are descoped with them. The remaining safety requirement (motor cutoff on excessive tilt) was met partially: an operator-initiated kill switch is delivered, where an automatic in-loop tilt cutoff was specified.
Failure mode analysis: loaded locomotion (Task 3b). The dynamic 5 kg failure is the most significant performance gap and deserves a precise analysis. The mechanism is geometric, not control- related, and the distinction matters for how the failure is addressed. The cargo platform sits above the wheel axle by the height of the intermediate chassis decks. The velocity loop produces motion by biasing the inner balance loop’s tilt setpoint, deliberately leaning the chassis in the commanded direction so that the inner loop will drive the wheels forward to chase the lean. Under load, the cargo mounted at the top of the chassis swings forward in an arc around the wheel axle as the chassis leans. The horizontal displacement of the cargo’s center of mass for a given lean angle scales with the height of the cargo above the axle. With 5 kg of cargo on the current chassis, the lean angle that the velocity loop must command to initiate even a small commanded velocity is large enough that the cargo’s center of mass crosses outside the wheel’s contact patch before the wheel can translate the chassis forward. Once the cargo center of mass exits the contact patch, gravity acts with a moment arm the motors cannot counter, and the chassis tips before the controller can recover.
This failure cannot be addressed by gain tuning, because the lean that produces the failure is the same lean the controller commands to initiate motion. Tightening the gains would let the controller fight small leans harder, but the architecture requires the chassis to lean to move, and any commanded motion under a high cargo crosses the geometric tipping margin. The failure is therefore architectural and admits two architectural fixes (developed in Section 7): scale up the wheel diameter so that the geometric tipping envelope is larger and the lean angle needed to produce a given translational acceleration is smaller, or lower the cargo platform toward or below the wheel axle so that the moment arm of the loaded center of mass is reduced. Either fix changes the geometry of the platform; both together would address the failure most robustly.
Failure mode analysis: surface dependence (Task 1). The carpet-versus-smooth-floor asymmetry observed in Section 4.4 is a secondary failure mode of the controller in its current form. Two contributing causes were identified. The first is the absence of a plant-adaptive control mechanism: the gain set tuned on carpet is applied unchanged on hardwood and tile, where the rolling-resistance damping that the carpet contributes is absent and the controller operates with less effective damping margin. The second is the wheel selection. The 8-inch polyurethane wheels were specified for traction on smooth warehouse-style flooring at higher loads than this robot applies, and on residential smooth flooring under this robot’s load they produce a small hard contact patch with little compliance. A softer or pneumatically-tired wheel would absorb small surface irregularities and provide some natural damping that the rigid polyurethane does not.
Comparison to related work. The CAMS-Bot result is consistent with the controls literature reviewed in Section 2. The cascaded PID architecture adopted from Petcu and Andreescu [14] and the Instructables reference build [16] produced stable balance behavior on the delivered system, confirming that PID is a sufficient control strategy for the inner balance loop on a small two-wheeled platform when implemented carefully (correct sign convention, derivative filtering, integral clamping, and a properly placed setpoint). The platform-level result, however, diverges from the cargo-andfollowing platforms in Section 2 in a way that highlights the gap CAMS-Bot was attempting to close. The Foxtech FOLO-200 commercial follower [10] solves the loaded-locomotion problem by being mechanically passive: it uses four wheels on a stable base and never has to lean to move, so the geometric tipping problem CAMS-Bot encountered does not arise. The inverted-pendulum platforms in the academic literature [14],
[15] typically demonstrate balance without payload, and where payload is included it is mounted close to the wheel axle rather than on a raised cargo platform, so the geometric tipping mode at large loaded leans is rarely encountered. The CAMS-Bot delivered system sits between these regimes: it adopts the residentially- scaled two-wheel form factor of the academic platforms but attempts to carry the residentiallymeaningful payload of the commercial follower class, and the geometric mismatch between those two ambitions on the current hardware is the dominant lesson of the evaluation. Implications for a more robust build. The analyses above imply a specific set of architectural changes for a follow-on build that would address the dominant failure modes.
(i) The wheels should be larger in diameter (in the range of 24–29 inches) and should be pneumatic rather than rigid polyurethane, both to extend the geometric tipping envelope under load and to provide passive compliance on smooth flooring. (ii) The chassis should be metal rather than the laser-cut acrylic and 3D-printed PETG and PLA of the current build, since metal admits a stiffer structure at the larger scale that the bigger wheels imply, and admits a solid drive axle through the chassis that would replace the current motor-mounted-to-deck arrangement. (iii) A solid axle through the chassis would let the cargo platform be mounted closer to or below the axle rather than only above it, which is the second of the two geometric fixes for the loaded-locomotion failure. (iv) The vision and tracking subsystem, descoped from the delivered build, completes the autonomous functional set and is the natural software addition once the platform is hardware-robust enough to carry a camera through the residential environment without falling. These changes are developed as concrete future-work items in Section 7.
Encoder-based velocity feedback was instrumental. A specific positive finding of the evaluation is that the outer velocity loop, driven by quadrature-encoder feedback from the two gearmotors, was essential rather than optional for the controllable behavior the delivered system achieves. A balance-only configuration with no velocity feedback (an inner-loop-only PID against tilt) holds the chassis upright in static balance, but cannot be commanded to drive in any controlled way and tends to drift on the floor under small asymmetries between the two motor channels. Adding the outer velocity loop, in which the encoder-derived wheel velocity is compared against the commanded drive value and used to bias the inner loop’s tilt setpoint, is what produces the actual translational and rotational behavior of the chassis under operator command. The cost of this addition is the extra tuning surface that comes with a second control loop, including the loop-rate divisor (VEL_LOOP_DIV) and a small set of velocity-loop gains that interact with the inner-loop gains during transients. The benefit is qualitatively different behavior: a robot that holds itself up versus a robot that holds itself up and can be driven and turned. For a follow-on build, or for any future team starting from a balance-only Instructables-class reference, the encoder-based velocity loop is recommended as essential infrastructure and not as an optional refinement, even though it roughly doubles the controller’s tuning surface.
V. PROJECT OUTCOMES AND IMPACT

The CAMS-Bot project delivered a working self-balancing two-wheeled cargo platform that satisfies the structural and balance components of the proposal’s headline 5 kg payload specification, accepts manual operator control through a ROS2 teleoperation stack and an Xbox controller, and demonstrates the cascaded PID control architecture appropriate to the inverted-pendulum form factor. Within the scope it occupies, the delivered system is functional: it balances reliably on residential carpet, responds smoothly to drive and turn commands, holds 5 kg in static balance, and provides operator-initiated motor cutoff through both a hardware kill switch and a serial stop command. The dynamic 5 kg locomotion case is the primary unmet specification, for the geometric reasons analyzed in Section 4.5, and the autonomous-following functional set was descoped with the withdrawal of the project partner responsible for the vision pipeline.
Impact on the target user population. The delivered system is appropriately characterized as an early proof of concept rather than a deployable assistive device. In its current form, the platform demonstrates that a residentially-scaled self-balancing cargo robot can be designed, fabricated, and made to work on an all-maker-space build path, and that a cascaded PID controller running on a single low-cost microcontroller can produce stable balance behavior sufficient to support the assistive task. These are genuine prerequisites for a residential cargo-following device of the kind motivated in Section 1, and demonstrating them on a working build is a non-trivial contribution. However, several specific architectural changes (larger and pneumatic wheels, a metal chassis with a solid drive axle, a cargo platform mounted at or below the axle, and the descoped vision pipeline) are required before the platform could plausibly serve a user in a residential environment. Those changes are developed as concrete future-work items in Section 7. The short-term impact of the project is therefore confined to the proof-of-concept role: it shows that the problem is tractable on a student budget and identifies the specific architectural gaps a follow-on build would need to close. The long-term impact is contingent on those gaps being closed; if they were, the platform class CAMS-Bot demonstrates would address a real and underserved residential need (Section 2).
Differences from the original proposal. The delivered system differs from the proposal in three categories of change.

First, several technical refinements were made during implementation that produced a more reliable build than the proposal specified: the L298N motor driver replaced the TB6612FNG, the balance controller was implemented in MicroPython rather than C++, and the Pi 4-to-Pico link was moved from USB CDC serial to hardware UART. These changes are detailed in Section 3.4 and were each driven by an integration problem that surfaced during development. Second, the safety mechanism delivered (an operator-initiated kill switch) is a partial substitute for the proposal’s automatic in-loop tilt cutoff. Third, and most significantly, the autonomous-following capability based on the OAK-D Pro and DepthAI was descoped with the partner withdrawal one week before the project deadline. The hardware to support that subsystem (the camera, the camera mount, and the command interface from the high-level node graph to the balance controller) is in place; the vision software that would have driven it is not. This reduces the delivered system from the proposal’s autonomous follower to a manually-driven balance platform with the assistive payload-carrying behavior preserved.

VI. LESSONS LEARNED

Unexpected technical challenges. The dominant technical surprise of the project was how much of a self-balancing controller’s behavior depends on a small number of non-obvious low-level details. The motor’s electrical start threshold was not visible in any motor datasheet specification, and discovering that PWM commands below the start threshold produce no motion at all (silently corrupting closed-loop behavior, since the controller believes it has applied a correction the plant ignored) cost more debugging time than any single classicalcontrols insight. Similar non-obvious lessons surfaced for the IMU boot sequence (a 2 s startup delay on the MPU6050 is the difference between reliable initialization and intermittent boot failures), the deadband state preservation (zeroing the previous-error and filtered-derivative state at deadband entry causes derivative spikes on re-entry), and the choice of serial transport (USB CDC blocking-read behavior is incompatible with a tight control-loop budget; hardware UART with non-blocking reads solved it cleanly). None of these appears in introductory PID literature, and each had to be discovered the hard way. The geometric tipping behavior of the loaded chassis (Section 4.5) was also unexpected: classical balance-bot tutorials demonstrate balance on lightly-loaded chassis where the cargo geometry never becomes limiting, so the lesson that high-mounted cargo on small wheels makes locomotion under load impossible regardless of gain tuning is not in the standard learning path.
What went well, and why. Three things went well. First, the cascaded PID architecture adapted from the Instructables reference build [16] worked as advertised once the low-level details above were resolved, and the encoder-driven outer velocity loop in particular was instrumental in making the platform actually controllable rather than merely upright (Section 4.5). Second, the split power and compute architectures (12 V motor bus separate from the USB battery logic supply; the Pico handling deterministic balance separately from the Pi 4’s ROS2 stack) avoided entire classes of bug that would have cost real time to diagnose, and the foresight to build this split early in the project paid for itself many times over. Third, the all-in-house CAD-to-fabrication path through the Northeastern FlexLab maker space, with laser-cut acrylic decks, 3D-printed PLA brackets, and PETG only at the highest-load wheel bushing, kept iteration time to hours rather than days; this mattered most during the wheel-bushing convergence cycle.
Decisions that would change in a follow-on build. Three architectural decisions would change. The wheel selection (8-inch polyurethane intended for warehouse flooring) is the single most consequential limiter of the delivered system’s behavior, both for the geometric tipping failure under load (Section 4.5) and for the carpet-versus-smooth-floor stability asymmetry. Larger pneumatic wheels would address both. The chassis material (laser-cut acrylic and 3D-printed plastic) is appropriate for the scale of the current build but does not extend to the larger-wheeled platform a follow-on build would need; a metal chassis with a solid drive axle through the chassis admits both the larger scale and the option of mounting the cargo platform at or below the axle, which is the second of the two geometric fixes for the loaded-locomotion failure. Finally, the evaluation infrastructure should have included automated logging of tilt-angle and encoder-velocity traces from the start of tuning, rather than relying on visible chassis behavior; the gain set the project converged to is acceptable but is not maximally tight, and a logged-trace retune would have produced a more quantitatively defensible controller in the same wall-clock time.
Recommendations for future teams. Future student teams attempting a similar build should know that the project is feasible on a near-zero parts budget through maker-space fabrication, but several specific items will save substantial debugging time. Set the minimum effective controller output above the motor’s electrical start threshold, not a nominal small value. Delay the first IMU read by a generous margin (2 s on the MPU6050) before starting the control loop. Filter the derivative term and clamp the integral term as a matter of course, not as an optimization. Preserve controller state across deadband transitions; do not zero it. Tune the balance setpoint before introducing KI , and use the encoder-driven outer loop from the start rather than treating it as an optional refinement. Use hardware UART rather than USB CDC for the link between high-level and low-level boards. Plan the chassis geometry so that the cargo platform is at or below the wheel axle, and select wheels large enough that the geometric tipping envelope under expected loads is comfortable. Finally, log control-loop signals to file from day one of tuning; visible behavior is sufficient to converge a controller, but logged traces are sufficient to converge it well.
Personal learning. The project required learning, from a base of no prior exposure, both classical control theory at the level needed to implement and tune a cascaded PID balance controller, and parametric mechanical CAD at the level needed to design every custom part on the robot. Both domains became genuinely usable through the iterative hardware-inthe-loop work the project required, in a way that classroomonly exposure does not produce. The delivered system is a proof of concept with known and specifically-articulated limitations rather than a deployable device, but it works, and it works well enough on the static portion of its headline specification to demonstrate that the class of platform CAMS-Bot represents is achievable on a student budget by a single author with maker-space access.

VII. LIMITATIONS AND FUTURE WORK

The delivered CAMS-Bot system has well-characterized limitations, identified through the evaluation in Section 4 and the analysis in Section 4.5. This section enumerates them and pairs each with concrete future work that would address it. The items are ordered roughly by impact on the assistive task: hardware geometry first, then control and operator interface, then software completeness.
Limitation: loaded locomotion fails (Task 3b). The current 8-inch wheels and the cargo platform mounted above the wheel axle produce a geometric tipping envelope too small to admit the lean required for loaded driving (Section 4.5). Future work: a chassis redesign using larger pneumatic wheels in the 24–29 inch range, a metal frame stiff enough at that scale, and a solid drive axle through the chassis. The solid axle admits two changes that the current motor-mounted-todeck arrangement does not: a structurally robust drive coupling between motor and wheel that does not depend on a 3D-printed bushing as the load path (see weak-point limitation below), and a cargo platform mounted at or below the axle plane to reduce the moment arm of the loaded center of mass.
Limitation: the wheel-to-motor coupling is the mechanical weak point. The PETG-printed wheel bushings (Bush_v2.stl) sit between the FIT0186 motor’s flatted D-shaft and the polyurethane wheel bore, and every newton-meter of motor torque passes through this single 3D-printed part. The bushings hold under the loads the current platform applies, but they are the part most likely to fail under the higher torques a heavier loaded build would impose, and a slipping or fatigued bushing produces the worst class of failure (silent loss of drive on one wheel, with the controller continuing to issue commands the chassis can no longer execute). Future work: a solid metal axle running through the chassis, with the wheels keyed to the axle and the motors driving the axle through a belt or chain reduction. This replaces the printed bushing as the load-path element and decouples wheel mounting from motor mounting, allowing each to be optimized independently. Limitation: stability is surface-dependent. The same gain set produces reliable balance on residential carpet but degraded behavior on hardwood and tile (Section 4.4). Two contributing causes were identified: the controller is non-adaptive across surfaces, and the polyurethane wheels were specified for warehouse flooring rather than residential surfaces. Future work: pneumatic wheels would provide passive compliance on smooth flooring that the current rigid polyurethane does not, addressing the wheel-side cause. A gain-scheduled or autotuning controller that adjusts gains in response to measured plant response would address the controller-side cause; a simple version schedules gains based on a surface-detection signal (for example, the variance of the tilt rate during quiet balance), and a more sophisticated version uses the encoder-velocity loop’s tracking error to identify plant conditions online.
Limitation: flat ground only. The platform was tested on level surfaces. Inclines and thresholds were not evaluated. Although no specific failure mode on inclines has been observed, the controller is non-adaptive (above), the velocity loop’s setpoint biasing assumes a level surface as the natural balance point, and the small wheel diameter does not roll over thresholds well. Future work: the larger pneumatic wheels and gain-scheduled controller above are prerequisites for inclined or threshold operation; explicit testing across inclines, hardwood-to-carpet transitions, and small thresholds would then validate the upgraded platform on the surface distribution of an actual residence.
Limitation: throttle control through the Xbox controller is coarse. The current drive-input shaping (Sec-
tion 3.4 and the MAX_DRIVE_ANGLE, VEL_DRIVE_SCALE, VEL_RAMP_RATE, and TRIGGER_EDGE parameters) pro-
duces controllable but coarse throttle response: the analog stick maps to lean angle and velocity target without a tunable response curve, and the operator does not have fine control at low speeds. Future work: introduce a configurable response curve on the analog input (an exponent or a piecewise-linear curve) so that small stick deflections produce small velocity targets with finer resolution, while full-stick deflection still produces the maximum lean. A second improvement is operator-tunable maximum lean and maximum velocity, exposed as ROS2 parameters on the teleoperation node rather than as firmware constants on the Pico, so that the same firmware can be used across operator preferences without re-flashing.
Limitation: safety relies on operator-initiated cutoff. The delivered safety mechanism is a hardware kill switch (Section 3.1, Section 3.4), which satisfies the operator-in-the-loop case but does not satisfy the proposal’s automatic in-loop tilt cutoff for fall-class events that complete faster than an operator can react. Future work: an automatic tilt-threshold cutoff in the Pico balance loop. The implementation is small: when the absolute tilt exceeds a threshold (for example, 30◦ ),
drive PWM to zero unconditionally and require an explicit operator reset before resuming. This is straightforward to add and is a high-priority safety improvement.
Limitation: the autonomous-following capability was descoped. The OAK-D Pro and DepthAI person-tracking pipeline that the proposal specified was not delivered (Section 3.4). The hardware to support it (camera, mount, USB connection to the Pi 4, and the same drive/turn command interface used by the manual teleoperation node) is in place. Future work: a vision and tracking node that runs on the Pi 4 in ROS2, performs YOLO-based person detection on the OAK-D Pro stream, estimates the user’s bearing and range relative to the chassis, and publishes drive and turn commands to the Pico through the same UART protocol the manual teleoperation node currently uses. The descoped safety requirements (stop on loss of detection, cap on autonomous-mode speed) would be implemented alongside this node.
Limitation: evaluation was qualitative rather than logged. The metrics in Section 4.4 are largely binary or qualitative, because the project’s instrumentation did not include logged tilt-angle, encoder-velocity, or controller-output traces. Future work: log these signals to file (or stream them to the Pi 4 over UART for recording) during all subsequent tuning and evaluation. Quantitative metrics such as RMS tilt error, velocity-loop tracking error, and disturbance-rejection time become available once the signals are logged, and the gains in Table III can be tightened against measured performance rather than visual inspection.

VIII. CONCLUSION

This report described CAMS-Bot, a self-balancing two-wheeled cargo platform developed for the EECE 5552 Assistive Robotics course as a step toward a residentially-scaled cargo-following device for users with mobility limitations. The motivating assistive task is the routine but high-leverage problem of transporting everyday items between rooms, a task that compounds the existing physical burden of users who rely on stability aids. Existing solutions either require the user to push the device (rollators and walkers) or are sized and priced for industrial environments rather than residential use, leaving a gap that CAMS-Bot was designed to address.
The delivered system is built around a Raspberry Pi 4 running ROS2 Jazzy in Docker for high-level control, a Raspberry Pi Pico running a cascaded PID balance controller in MicroPython at 100 Hz, an MPU6050 IMU for tilt sensing, two 12 V DC gearmotors with quadrature encoders driving 8-inch polyurethane wheels through an L298N H-bridge, and a hybrid chassis built from laser-cut acrylic decks, 3D-printed PLA brackets, and PETG bushings at the wheel-tomotor coupling. An Xbox controller provides operator input through a ROS2 teleoperation node that forwards drive and turn commands to the Pico over a hardware UART link. The platform balances reliably on residential carpet, accepts smooth teleoperated drive and turn commands, and successfully holds the project’s headline 5 kg payload in static balance. The dynamic 5 kg locomotion case fails for analyzed geometric reasons, and the autonomous person-following capability was descoped with the withdrawal of the project partner responsible for the vision pipeline. The principal contributions of the project are a working residentially-scaled self-balancing cargo platform built on a near-zero-cost maker-space fabrication path, a fully documented cascaded PID controller including several non-obvious low-level practices (smooth deadband feedforward, state-preserving deadband, stiction-overcome kick, complementary IMU fusion) that are essential to the platform’s behavior, and a clear architectural roadmap (Section 7) for the follow-on build that would extend the platform from proof of concept to deployable assistive device.

REFERENCES

[1] Centers for Disease Control and Prevention, “Disability impacts all of us infographic,” https://www.cdc.gov/disability-and-health/articles-documents/disability-impacts-all-of-us-infographic.html, (https://www.cdc.gov/disability-and-health/articles-documents/disability-impacts-all-of-us-infographic.html) July 2024, national Center on Birth Defects and Developmental Disabilities. Accessed: 2026-03-09.
[2] Disabled World, “Mobility device statistics: United States,” https: //www.disabled-world.com/disability/statistics/mobility-stats.php, October 2022, accessed: 2026-03-09.
[3] T. L. Chen, M. Ciocarlie, S. Cousins, P. M. Grice, K. Hawkins, K. Hsiao,
C. C. Kemp, C.-H. King, D. A. Lazewatsky, A. E. Leeper et al., “Robots for humanity: using assistive robotics to empower people with disabilities,” IEEE Robotics & Automation Magazine, vol. 20, no. 1, pp. 30–39, 2013.
[4] P. Balatti, I. Ozdamar, D. Sirintuna, L. Fortini, M. Leonori, J. M. Gandarias, and A. Ajoudani, “Robot-assisted navigation for visually impaired through adaptive impedance and path planning,” 2023. [Online]. Available: https://arxiv.org/abs/2310.14705
[5] A. Deb, Z. Wypych, J. Lonner, and H. Ashrafiuon, “Design and control of an autonomous robot for mobility-impaired patients,” IFAC-PapersOnLine, 2021. [Online]. Available: https://www.sciencedirect.com/science/article/pii/S2405896321022254 (https://www.sciencedirect.com/science/article/pii/S2405896321022254)
[6] S. A. Olatunji, J. S. Shim, A. Syed, Y.-L. Tsai, A. E. Pereira, H. P. Mahajan, R. A. Mudar, and W. A. Rogers, “Robotic support for older adults with cognitive and mobility impairments,” Frontiers in Robotics and AI, 2025. [Online]. Available: https://www.frontiersin.org/journals/robotics-and-ai/articles/10.3389/frobt.2025.1545733/full (https://www.frontiersin.org/journals/robotics-and-ai/articles/10.3389/frobt.2025.1545733/full)
[7] A. Steinfeld, T. Fong, D. Kaber, M. Lewis, J. Scholtz, A. Schultz, and M. Goodrich, “Common metrics for human-robot interaction,” in Proceedings of the 1st ACM SIGCHI/SIGART conference on Human-robot interaction, 2006, pp. 33–40.
[8] S. G. Hart, “Nasa-task load index (nasa-tlx); 20 years later,” in Proceedings of the human factors and ergonomics society annual meeting, vol. 50, no. 9. Sage publications Sage CA: Los Angeles, CA, 2006, pp. 904–908.
[9] J. R. Lewis, “Measuring perceived usability: The csuq, sus, and umux,” International Journal of Human–Computer Interaction, vol. 34, no. 12, pp. 1148–1156, 2018.
[10] Foxtech, “FOLO-200 heavy duty 100kg four-wheel cargo trolley
automatic human-following cart robot,” https://store.foxtech.com/folo-200-heavy-duty-100kg-four-wheel-cargo-trolley-automatic-human-following-cart-robot/, (https://store.foxtech.com/folo-200-heavy-duty-100kg-four-wheel-cargo-trolley-automatic-human-following-cart-robot/) 2024, foxtech Store. Accessed: 2026-03-09.
[11] KTLA, “Food delivery robot goes rogue, causes property damage
at | East | Hollywood | home,” | https://ktla.com/news/local-news/
food-delivery-robot-goes-rogue-causes-property-damage-at-east-hollywood-home/, (https://ktla.com/news/local-news/food-delivery-robot-goes-rogue-causes-property-damage-at-east-hollywood-home/) 2023, kTLA 5 News. Accessed: 2026-03-09.
[12] ABC7, | “Man | with | cerebral | palsy | repeatedly | hit | by
delivery | robot | in | West | Hollywood,” | https://abc7.com/post/
delivery-robot-hits-man-cerebral-palsy-mobility-scooter-west-hollywood/ 17866465/, (https://abc7.com/post/delivery-robot-hits-man-cerebral-palsy-mobility-scooter-west-hollywood/17866465/) September 2023, accessed: 2026-03-09.
[13] FOX | 11 | Digital | Team, | “Food | delivery | robot, | ambu-
lance | collide | in | Hollywood,” | https://www.foxla.com/news/
food-delivery-robot-ambulance-collide-in-hollywood, (https://www.foxla.com/news/food-delivery-robot-ambulance-collide-in-hollywood) January 2026, fOX 11 Los Angeles. Accessed: 2026-03-09.
[14] R. Petcu and G.-D. Andreescu, “Two-wheeled inverted-pendulum self-balancing robot with LQR or PID control,” in 2022 IEEE Conference, 2022. [Online]. Available: https://ieeexplore.ieee.org/document/9922862/ (https://ieeexplore.ieee.org/document/9922862/)
[15] S. Saha et al., “Epersist: A two-wheeled self balancing robot using PID controller and deep reinforcement learning,” in 2022 IEEE 19th India Council International Conference (INDICON), 2022. [Online]. Available: https://ieeexplore.ieee.org/document/10003940/
[16] Instructables, | “Arduino | based | self-balancing | bot,” | https:
//www.instructables.com/Arduino-Based-Self-Balancing-Bot/, | 2024,
accessed: 2026-03-09.

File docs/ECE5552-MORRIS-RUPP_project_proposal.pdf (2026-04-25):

# CAMS-Bot: An Autonomous Load-Carrying Follower Robot

Timothy Morris
Department of Electrical and Computer Engineering Northeastern University
Seattle, WA, USA
morris.t@northeastern.edu

Jason Rupp
Department of Electrical and Computer Engineering Northeastern University
Seattle, WA, USA
rupp.j@northeastern.edu
I. MOTIVATION

The target population for this assistive technology is those with mobility impairments, such as those who need an assistive device to walk or a wheelchair. Mobility impairment is the most prevalent disability among U.S. adults. According to the CDC, 12.2% of U.S. adults experience serious difficulty walking or climbing stairs, and 7.7% have an independent living disability characterized by difficulty performing errands alone [1]. These two populations overlap significantly and both could benefit from assistive devices. Mobility disability is particularly common among middle-aged adults, affecting nearly one in five, and among older adults, affecting approximately one in four [1]. The consequences of limited mobility extend beyond inconvenience. Users of mobility devices face significant challenges in achieving independence; the vast majority report difficulty using public transit — for many, it is insurmountable — and a majority cannot leave their homes without encountering steps [2]. Load carrying, such as grocery shopping, is among the most routine yet physically demanding daily tasks for this population and often necessitates reliance on another person. Although autonomous follower robots are commercially available, some will be outlined later in the report, none are specifically designed as assistive technology for individuals with mobility impairments. There are numerous reports of autonomous delivery robots gone awry, causing damage to gardens [3], colliding with emergency response vehicles [4], and endangering sidewalk users [5]. This system would not only need to be aware of the user it needs to follow, but also of its surroundings. What also makes this technically challenging is that the robot’s design is self-balancing. The act of balancing will need to be adaptive to the load mass the robot is carrying. A self-balancing design may introduce some unnecessary challenges and overall load-carrying weight, but it would be more agile and able to maneuver in tight spaces with only two wheels. This prototype is targeting users in residential settings where the ability to work in confined spaces will be an advantage, even though other sacrifices will be required. CAMS-Bot is a self-balancing two-wheeled autonomous follower robot designed specifically as assistive technology for individuals with mobility impairments, autonomously carrying loads over distances. The robot can carry loads up to 5 kg and is designed to autonomously follow its user through residential environments at walking speeds of 0.5–1.5 m/s. The system uses a depth camera for person-following and obstacle avoidance, a real-time balance controller running on a dedicated microcontroller, and a single-board computer for high-level navigation and user interaction. An Xbox controller or other Bluetooth-capable device interface provides a manual override mode, ensuring the user always remains in control. By autonomously carrying loads, CAMS-Bot aims to reduce physical strain and extend the functional independence of users who would otherwise rely on a caregiver for assistance. The prototype targets indoor and residential use cases, where its compact two-wheeled form factor provides a maneuverability advantage over wider multi-wheeled platforms in confined spaces such as hallways and doorways.

II. RELATED WORK

A. Target User and Context
The target population for CAMS-Bot — individuals with mobility impairments who use assistive devices such as canes, walkers, or wheelchairs — faces a largely unaddressed gap in assistive robotics. While robotic assistance for mobility-impaired users has received growing research attention, existing systems focus predominantly on fall prevention and gait assistance rather than load carrying. Prior work, such as an autonomous fall-prevention follower robot by Vogt et al. [6], demonstrates the viability of autonomous person-following for mobility-impaired users, but focuses on physical support rather than cargo transport. Research into robot-assisted navigation for the visually impaired has explored adaptive impedance control and path planning to guide users through environments [7], yet this work similarly does not address the load-carrying need. Similarly, participatory design studies with older adults using the Stretch mobile manipulator found that item delivery and load carrying were among the most desired but underserved robotic assistance tasks [8]. These findings motivate the design of a system specifically tailored to the load-carrying need.
B. Existing Technical Approaches
The closest commercial parallel is Foxtech’s FOLO series — the FOLO-200, for example, is a heavy-duty cargo trolley with automatic human-following technology capable of carrying up to 100 kg [9]. However, this and similar products are designed for warehouses and industrial logistics, not residential environments, and not specifically for users with disabilities. They require the user to carry a dedicated handheld tracking device, are built for flat industrial floors, and are not designed around the constraints of a mobility-impaired user navigating a community or residential environment. CAMS-Bot targets this underserved space by combining person-following via a depth camera with a self-balancing two-wheeled platform optimized for confined indoor spaces, without requiring the user to wear or carry any tracking device.
On the control side, two-wheeled self-balancing robots are a well-studied platform, typically modeled as wheeled inverted pendulums. PID-based balance controllers have been widely demonstrated [10], [11], with cascaded control architectures separating the inner balance loop from the outer velocity loop being a common approach. Person-following using depth cameras has also been explored extensively, with stereo and RGB-D camera systems enabling robust target tracking in indoor environments [12]. CAMS-Bot builds on these established techniques, applying them in a novel assistive context where balance must remain stable under a variable payload — a constraint not addressed in prior self-balancing robot literature.

III. SYSTEM OVERVIEW

A. Design Requirements
Functional Requirements:
- The robot shall carry payloads up to 5 kg while maintaining balance.
- The robot shall autonomously follow its user at walking speeds of 0.5–1.5 m/s.
- The robot shall maintain a safe following distance of 0.5– 1.0 m behind the user.
- The robot shall detect and stop for obstacles in its path.
- The robot shall not require the user to wear or carry any tracking device.
Usability Requirements:
- The robot shall provide a manual override mode accessible via a Bluetooth gamepad controller, allowing the user to pause, redirect, or stop the robot at any time.
- The robot shall fit through a standard residential doorway. Safety Requirements:
- The robot shall cut motor output immediately if tilt angle exceeds a safe threshold.
- The robot shall stop immediately upon loss of user detection.
- The robot shall not exceed 1.5 m/s in autonomous following mode.
B. Robot Platform
CAMS-Bot is built on a custom 3D-printed and wood-reinforced chassis, designed to accommodate 8-inch polyurethane wheels for traction in residential environments. The drivetrain consists of two DFRobot FIT0186 12V DC

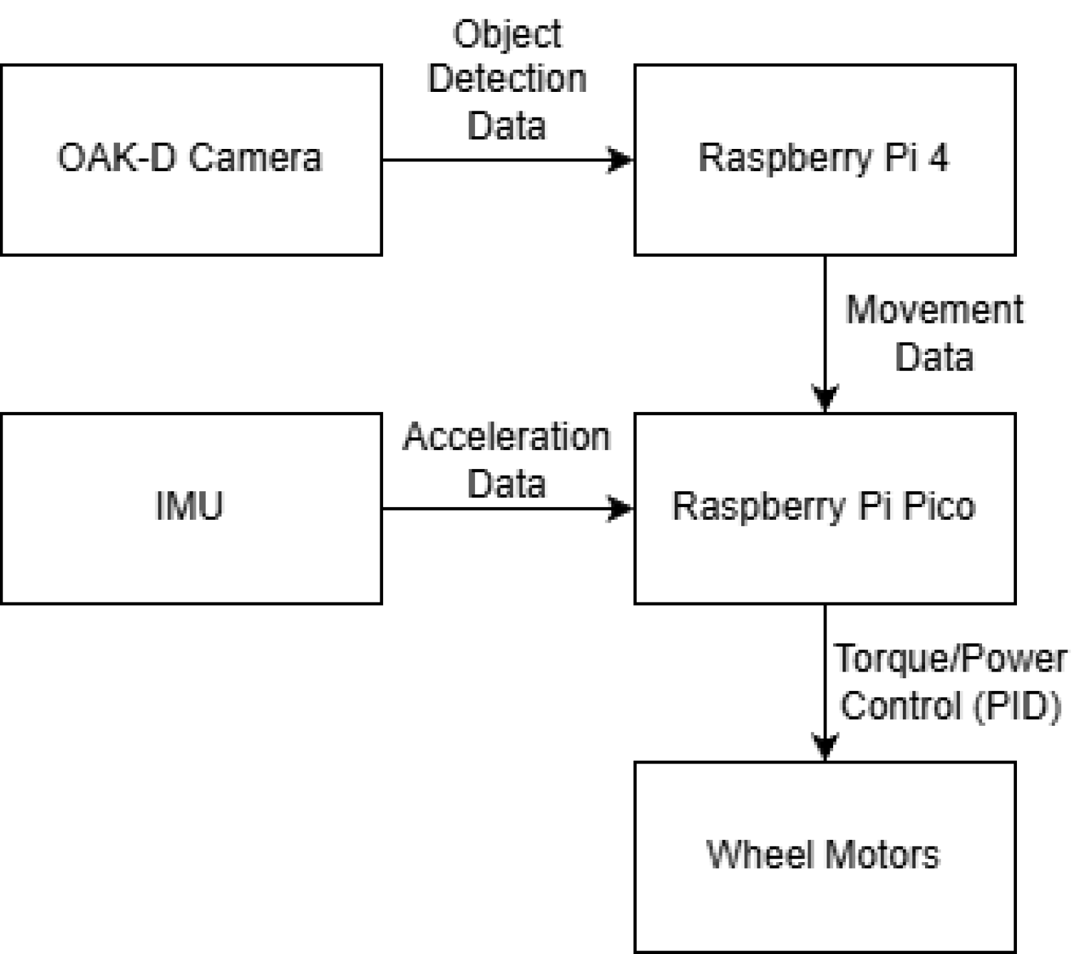
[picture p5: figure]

Fig. 1. System block diagram showing the two-layer compute architecture.
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

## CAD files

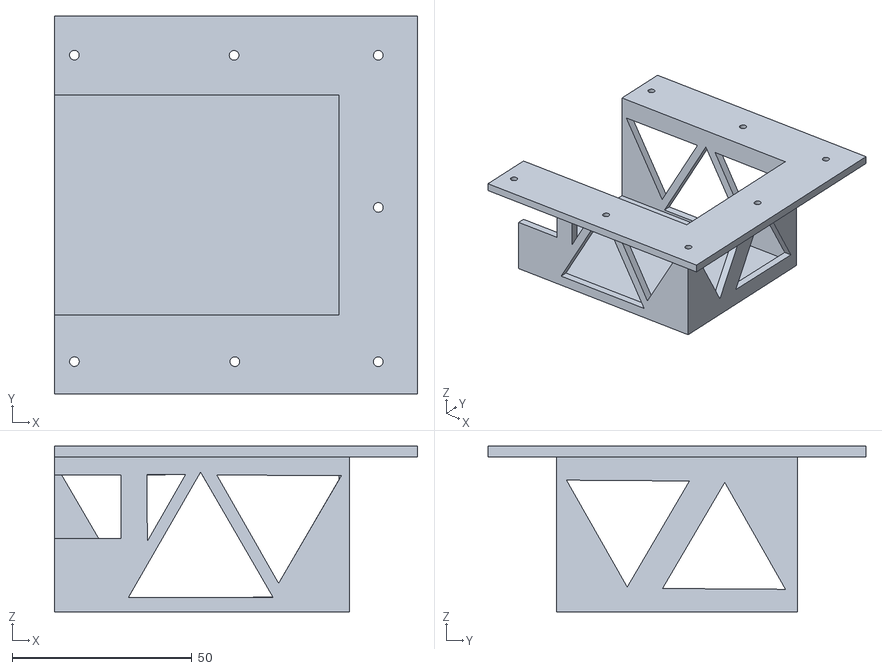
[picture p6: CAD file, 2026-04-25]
hardware/motor_battery_holder.stl
100.9 x 105.0 x 46.0

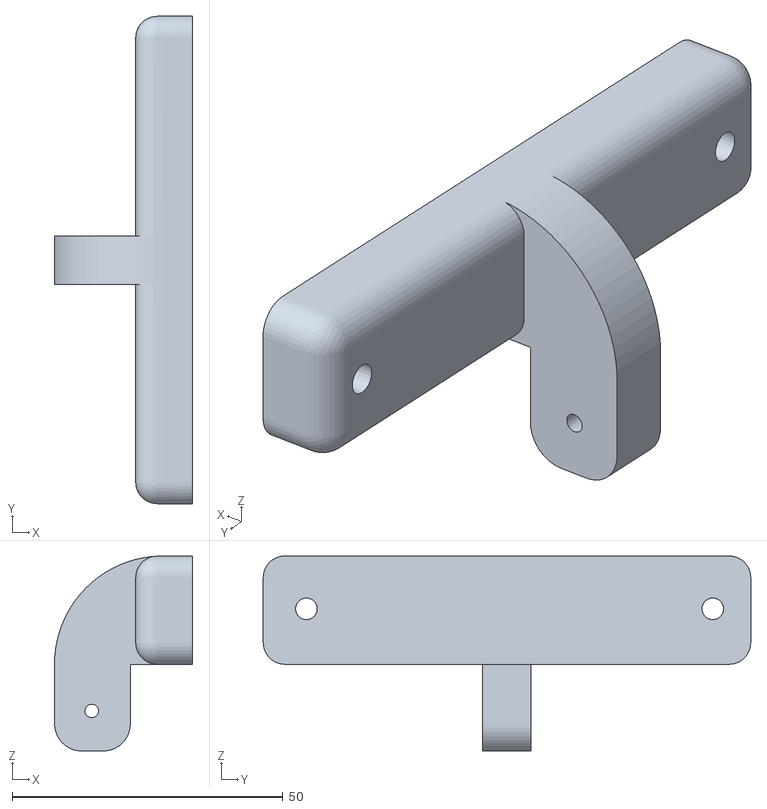
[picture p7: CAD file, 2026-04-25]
hardware/oak-d_mount.stl
25.5 x 90.0 x 36.0

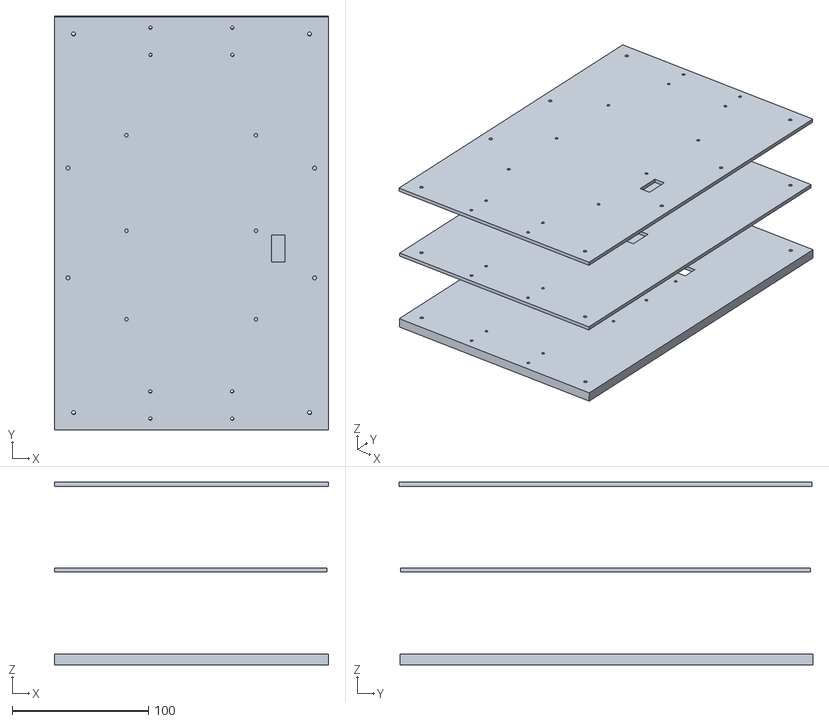
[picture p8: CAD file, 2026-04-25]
hardware/cams_redesign.stl
201.1 x 303.5 x 134.0

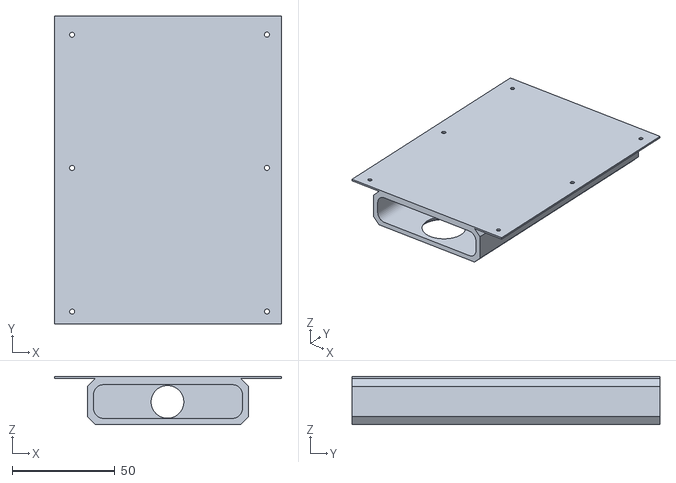
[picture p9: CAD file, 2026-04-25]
hardware/anker_battery_holder.stl
110.7 x 150.0 x 23.5

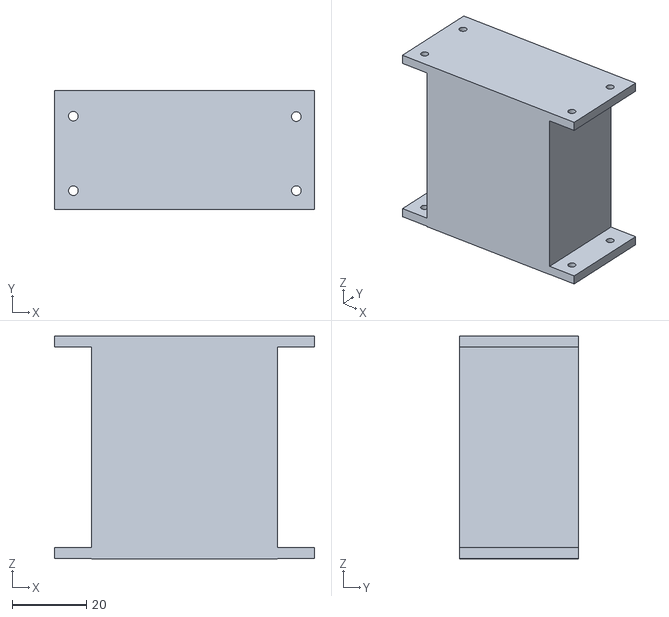
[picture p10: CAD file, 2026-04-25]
hardware/Motor_holder_dummy_BOTTOM.stl
70.0 x 32.0 x 60.0

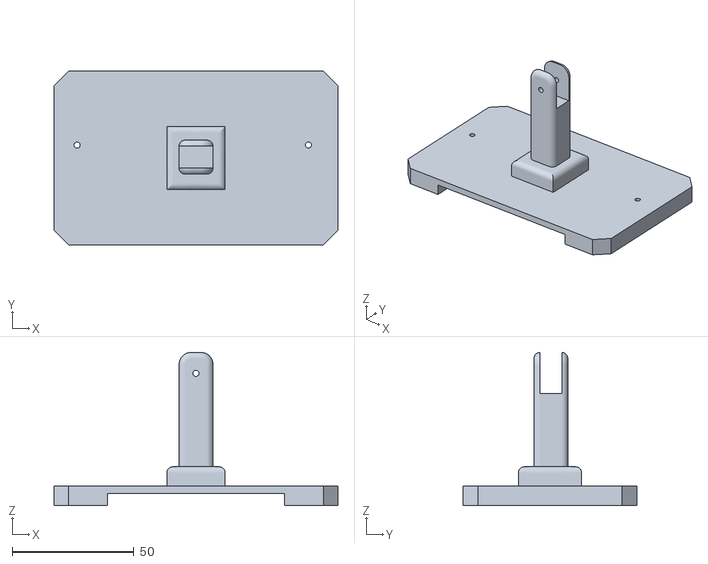
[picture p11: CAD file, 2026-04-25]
hardware/camera_mount.stl
116.8 x 71.4 x 63.0

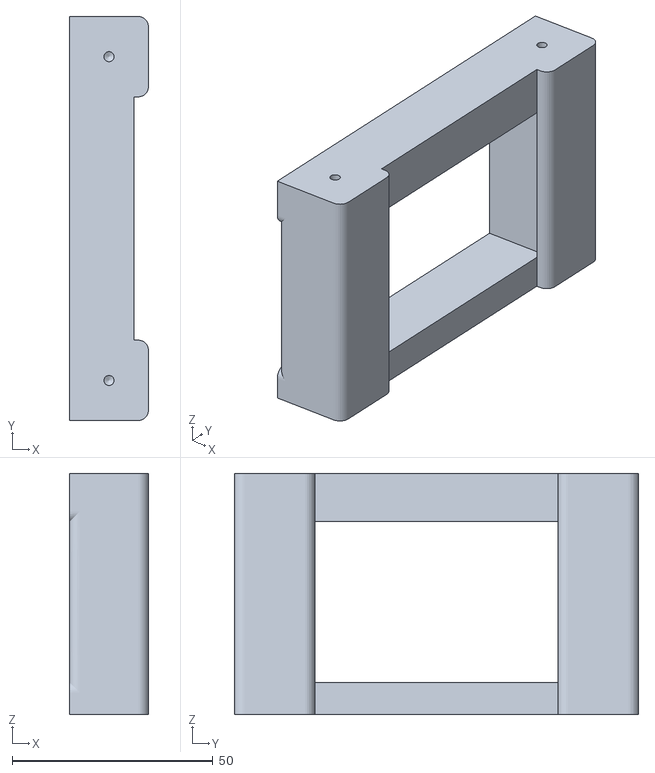
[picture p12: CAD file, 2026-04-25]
hardware/middle_support.stl
19.6 x 100.5 x 60.0

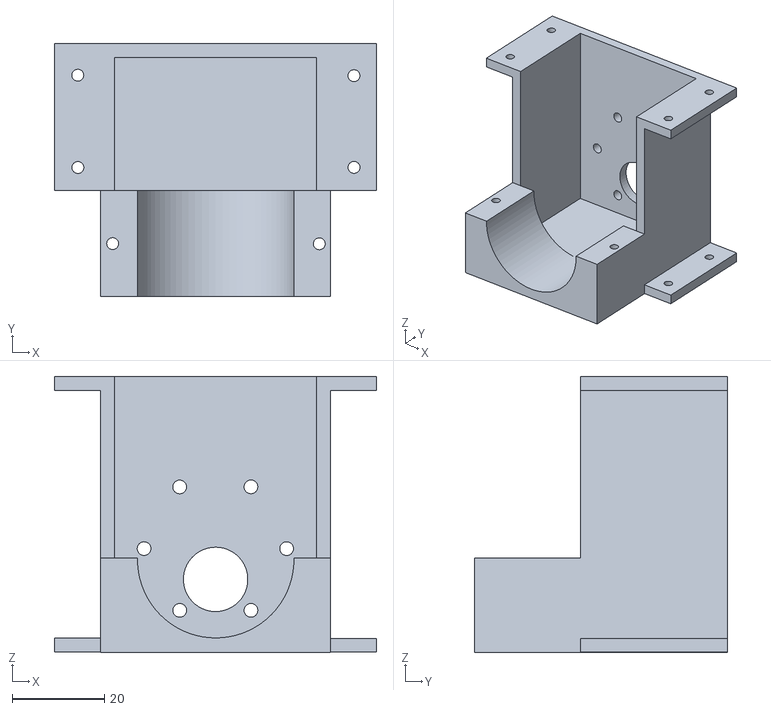
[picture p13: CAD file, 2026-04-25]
hardware/Motor_holder_FIT0186_BOTTOM.stl
70.0 x 55.0 x 60.0

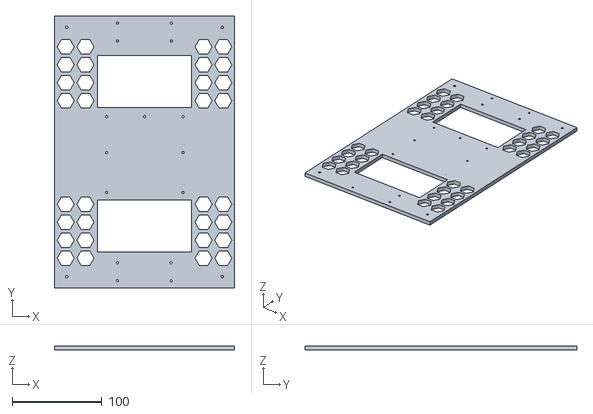
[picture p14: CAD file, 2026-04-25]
hardware/cams_redesign_support.stl
201.0 x 303.0 x 5.00

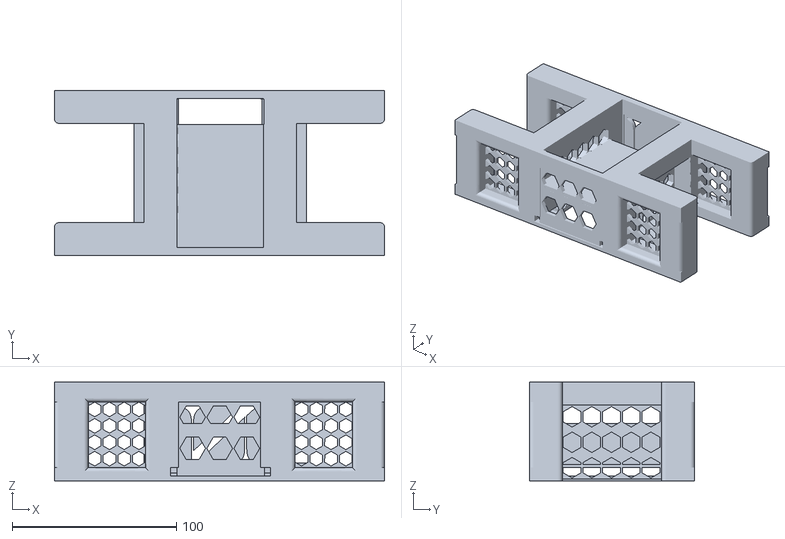
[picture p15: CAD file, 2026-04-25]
hardware/bottom_support.stl
201.0 x 100.5 x 60.0

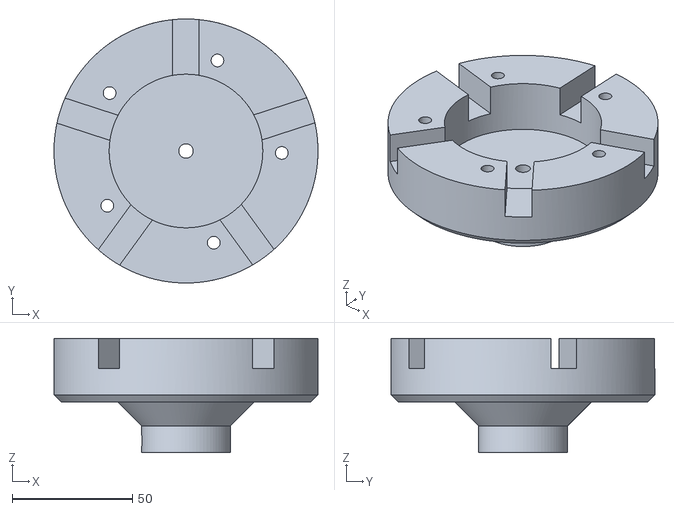
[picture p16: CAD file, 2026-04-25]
hardware/Bush_v2.stl
110.0 x 110.0 x 47.5

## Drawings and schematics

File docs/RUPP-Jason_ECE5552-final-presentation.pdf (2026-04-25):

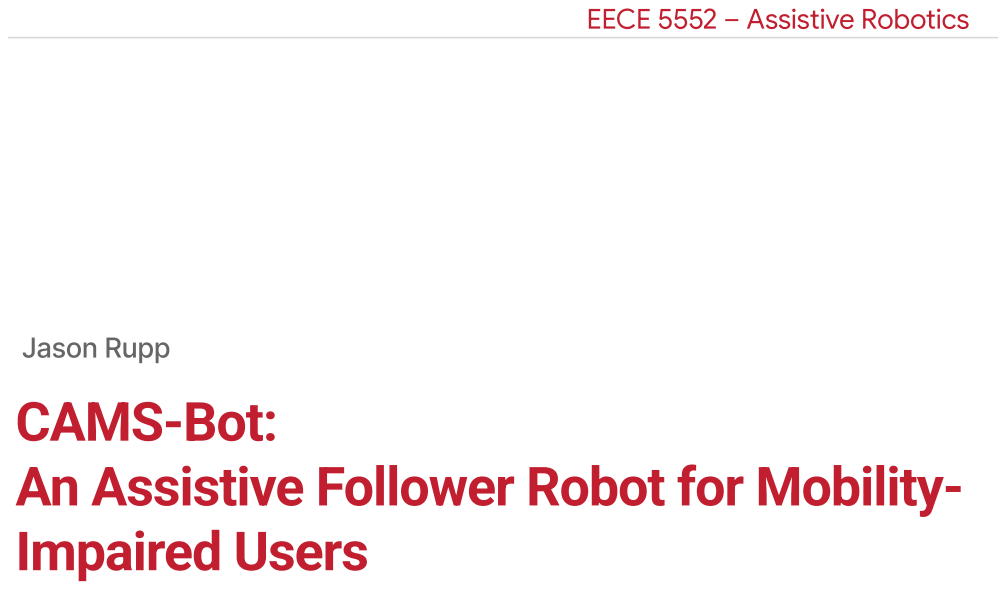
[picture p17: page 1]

Jason Rupp
CAMS-Bot:
An Assistive Follower Robot for Mobility-
Impaired Users

## Agenda

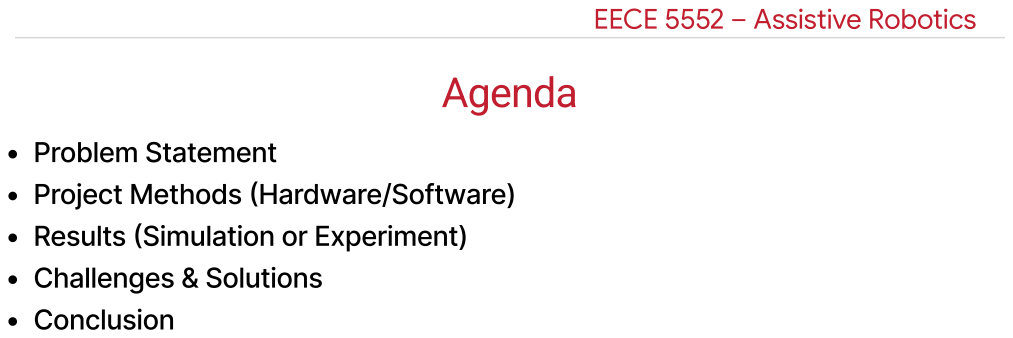
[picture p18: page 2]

Problem Statement
Project Methods (Hardware/Software)
Results (Simulation or Experiment)
Challenges & Solutions
Conclusion

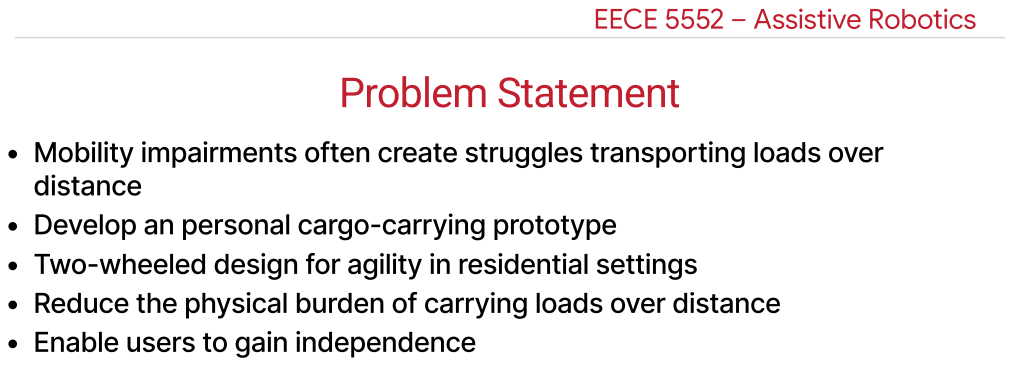
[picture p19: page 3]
Problem Statement

Mobility impairments often create struggles transporting loads over
distance
Develop an personal cargo-carrying prototype
Two-wheeled design for agility in residential settings
Reduce the physical burden of carrying loads over distance
Enable users to gain independence

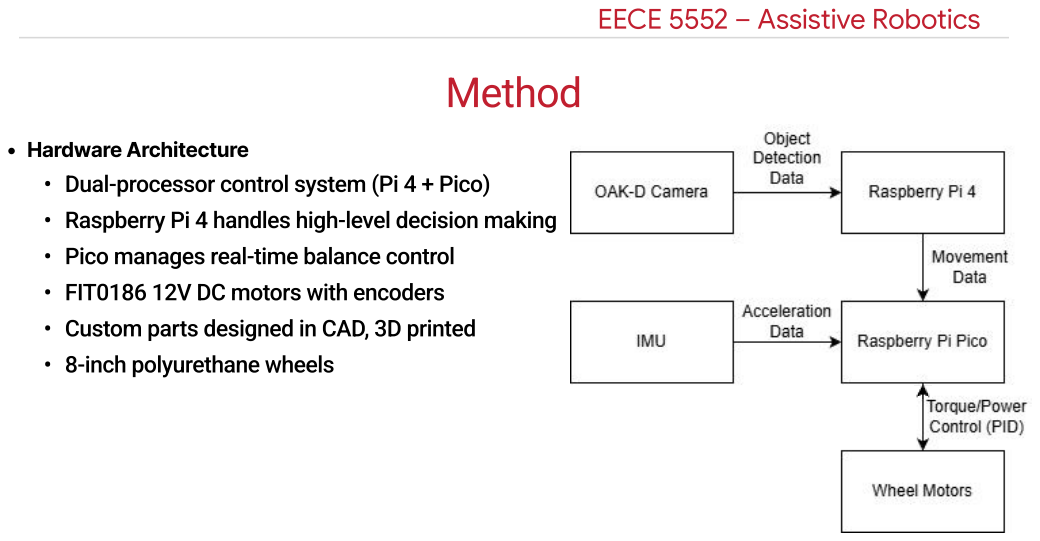
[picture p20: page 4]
Method

Hardware Architecture
Dual-processor control system (Pi 4 + Pico)

Raspberry Pi 4 handles high-level decision making

Pico manages real-time balance control

FIT0186 12V DC motors with encoders

Custom parts designed in CAD, 3D printed

8-inch polyurethane wheels

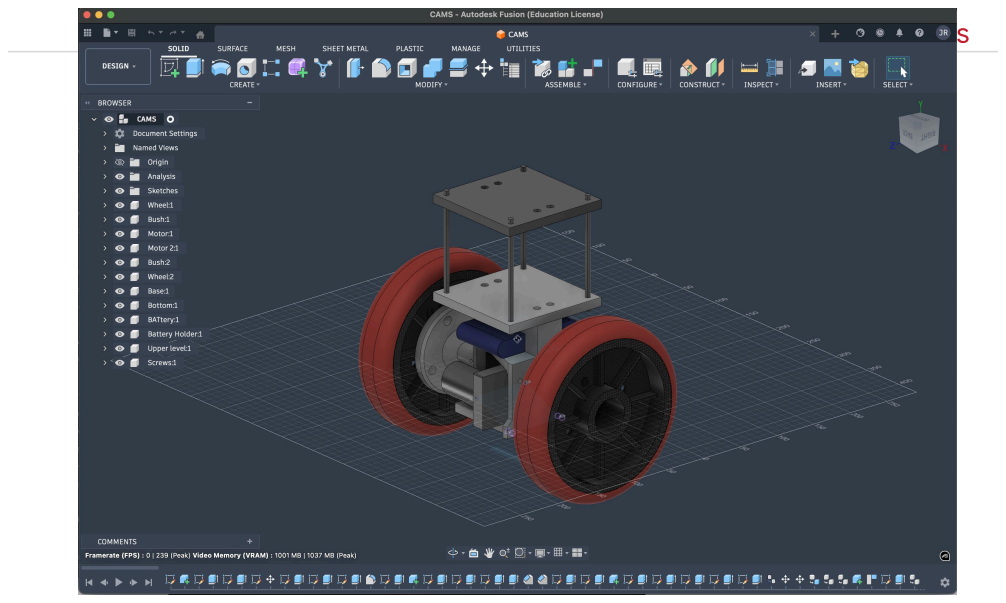
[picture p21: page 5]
Outcomes

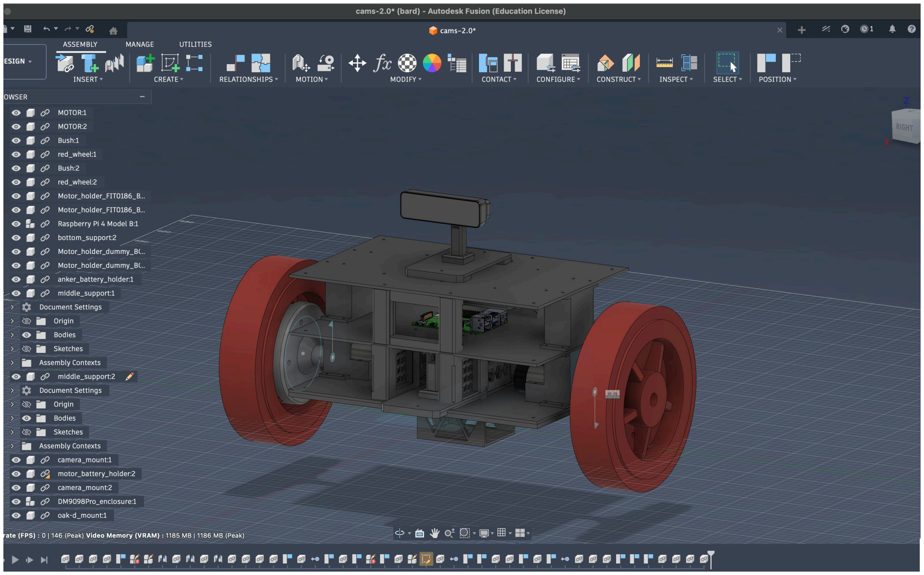
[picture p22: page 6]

## Method

Custom Made Parts

## Method

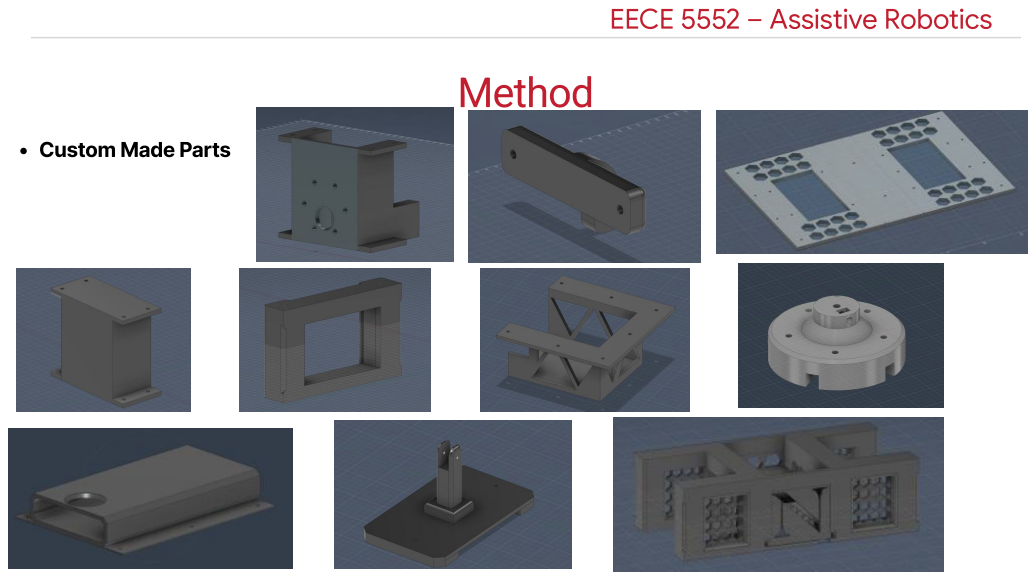
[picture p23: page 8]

Custom Made Parts

# Method

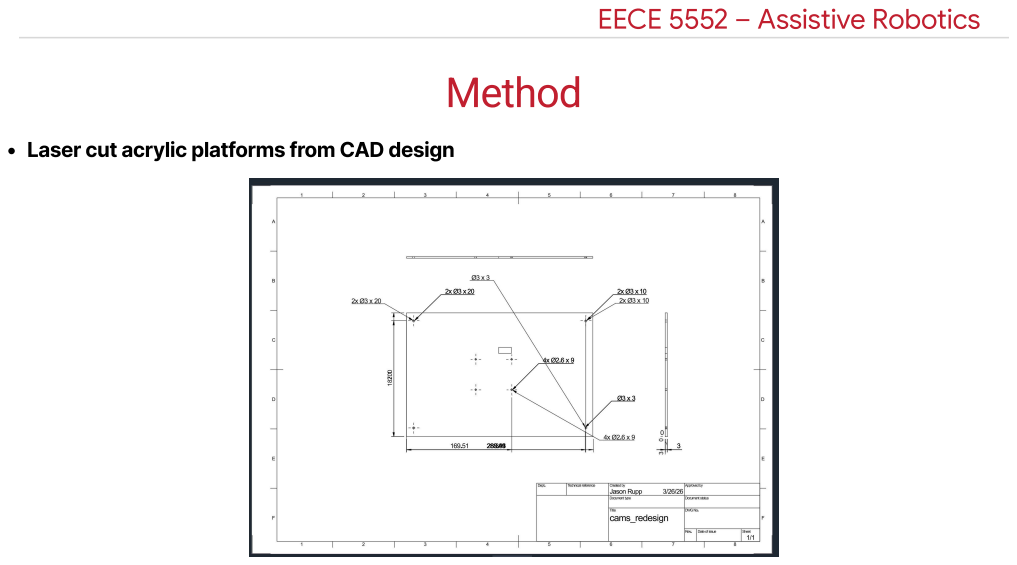
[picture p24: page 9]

Laser cut acrylic platforms from CAD design

## Method

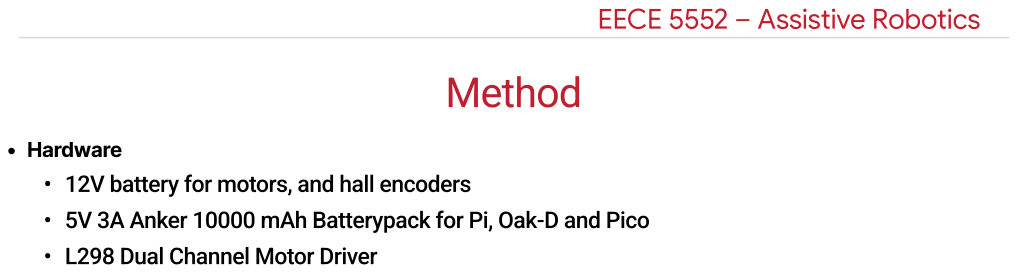
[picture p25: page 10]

Hardware
12V battery for motors, and hall encoders
5V 3A Anker 10000 mAh Batterypack for Pi, Oak-D and Pico
L298 Dual Channel Motor Driver

# Method

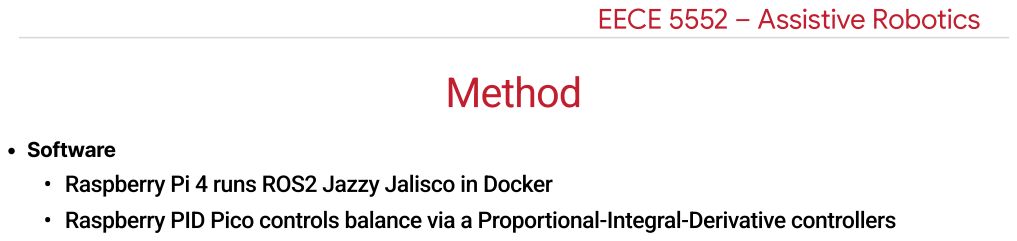
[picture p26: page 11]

Software
Raspberry Pi 4 runs ROS2 Jazzy Jalisco in Docker
Raspberry PID Pico controls balance via a Proportional-Integral-Derivative controllers

# Method

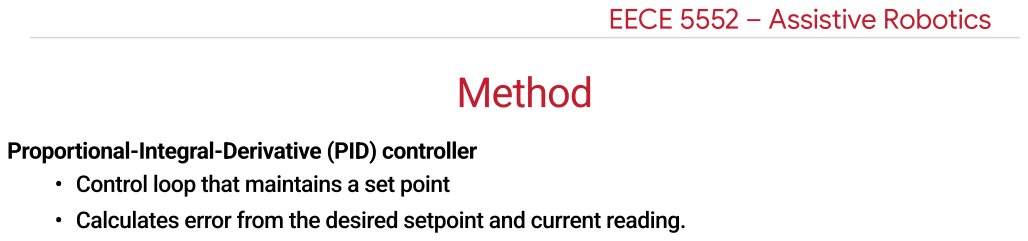
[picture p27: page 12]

Proportional-Integral-Derivative (PID) controller
Control loop that maintains a set point
Calculates error from the desired setpoint and current reading.

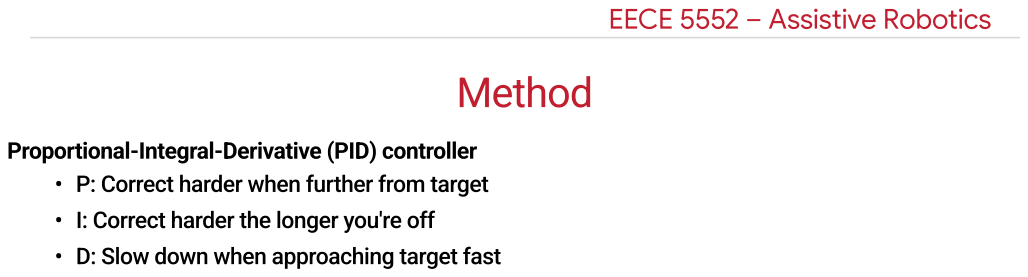
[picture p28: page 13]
Method

Proportional-Integral-Derivative (PID) controller

P: Correct harder when further from target

I: Correct harder the longer you're off

D: Slow down when approaching target fast

## Method


Proportional-Integral-Derivative (PID) controller
PID Controllers for angle (IMU) & velocity (Encoders)
PD only for lean angle - P alone oscillates — D dampens overshoot
PI only for lean angle - P alone drifts — I eliminates steady-state error

Hardware

## Live Demo

# Challenges & Solutions

# Challenges & Solutions


Conclusion

Conclusion

Conclusion

## Questions

References

https://www.cdc.gov/disability-and-health/articles-documents/disability-impacts-all-of-us-
infographic.html (https://www.cdc.gov/disability-and-health/articles-documents/disability-impacts-all-of-us-infographic.html)

https://store.foxtech.com/human-following-robot/

https://www.instructables.com/Arduino-Based-Self-Balancing-Bot/

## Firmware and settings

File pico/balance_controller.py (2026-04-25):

"""
CAMS Bot — cascaded PID balance controller
Pico MicroPython  |  MPU-6050 (I2C)  |  L298N dual H-bridge
Encoders: FIT0186 hall quadrature, 2797 ticks/rev

Wiring
------
MPU-6050
  SDA -> GP0   SCL -> GP1   VCC -> 3V3   GND -> GND

L298N  (Motor A = left, Motor B = right)
  ENA -> GP2  (PWM)   IN1 -> GP3   IN2 -> GP4
  ENB -> GP5  (PWM)   IN3 -> GP6   IN4 -> GP7

Encoders
  Left:   A -> GP12  B -> GP13   (inverted)
  Right:  A -> GP10  B -> GP11

UART1 (commands from Pi 4, 115200 baud)
  TX -> GP8   RX -> GP9

Serial commands
  D<float>,T<float>,B<float>\n  — drive, turn, boost (joystick ±1.0, trigger 0–1)
  S\n                           — stop (smooth ramp-down)
  K\n                           — kill switch: stop motors and zero state
  R\n                           — resume from kill

Drive model
  Joystick D value: lean offset for balance setpoint
  Joystick T value: differential PWM for turning
  Right trigger B value: forward throttle (sets velocity setpoint)

Motor deadband compensation (smooth)
------------------------------------
Measured: L298N + FIT0186 motors don't start spinning until ~30000 PWM
under load. Without compensation, the PID issues commands the motors
ignore until output gets large, then slams.

This file uses a SMOOTH ramp instead of an abrupt step at MIN_CMD:
- output near zero          → near-zero motor PWM (no jolt)
- output up to TRANSITION   → offset ramps linearly from 0 → MOTOR_OFFSET
- output above TRANSITION   → full MOTOR_OFFSET added

This avoids the "instant 30k step at zero crossing" that causes 10Hz
limit-cycle oscillation around the setpoint.
"""

from machine import Pin, PWM, I2C, UART
import struct, time, math

# ── Inner loop (balance) tuning ───────────────────────────────────────────────
SETPOINT       =  -1.0    # base tilt target (degrees)
KP             =  1000.0
KI             =  0.0
KD             =  700.0
LOOP_HZ        =  100
DEADBAND       =  0.3    # degrees
MAX_OUTPUT     =  65535
ALPHA          =  0.98    # complementary filter
D_FILTER_ALPHA =  0.3     # derivative low-pass
OUTPUT_FILTER  =  0.3

DT = 1.0 / LOOP_HZ

INTEGRAL_ZONE  = 2.0
INTEGRAL_CLAMP = 8.0

# ── Motor deadband feedforward (smooth) ──────────────────────────────────────
# MIN_CMD: below this absolute output value, motor is fully off (true zero)
# MOTOR_OFFSET: full offset added at and above TRANSITION
# TRANSITION: PID output value at which the offset becomes fully active.
#   Below TRANSITION, offset scales linearly from 0 → MOTOR_OFFSET.
#   This avoids an abrupt PWM step at zero-crossing that causes oscillation.
MIN_CMD        = 100
MOTOR_OFFSET   = 30000
TRANSITION     = 2800

# ── Drive scaling ─────────────────────────────────────────────────────────────
MAX_DRIVE_ANGLE = 1.5       # degrees of lean at full stick
VEL_DRIVE_SCALE = 5500.0    # full trigger → ±3700 ticks/sec velocity target
TURN_SCALE      = 10000.0   # ±0.3 max turn → ±4500 PWM differential

# Ramp rates — how fast the "current" value chases the "target" value
VEL_RAMP_RATE   = 4000.0
DRIVE_RAMP_RATE = 8.0

# Kick — overcomes stiction when starting from rest
KICK_PWM      = 12000.0
KICK_DECAY    = 0.88
KICK_MIN      = 200.0
TRIGGER_EDGE  = 0.2

# ── Outer loop (velocity) tuning ─────────────────────────────────────────────
VEL_KP = 0.002
VEL_KI = 0.0006
VEL_KD = 0.0
VEL_LOOP_DIV        =  10
VEL_SETPOINT        =  0.0
VEL_SETPOINT_TARGET =  0.0
VEL_INTEGRAL_CLAMP  =  1.5
VEL_MAX_OFFSET      =  2.0
VEL_D_FILTER        =  0.08

# ── Encoder config ────────────────────────────────────────────────────────────
TICKS_PER_REV = 2797

# ── Encoder class ─────────────────────────────────────────────────────────────
class Encoder:
    def __init__(self, pin_a, pin_b, invert=False):
        self.ticks = 0
        self.sign = -1 if invert else 1
        self.a = Pin(pin_a, Pin.IN, Pin.PULL_UP)
        self.b = Pin(pin_b, Pin.IN, Pin.PULL_UP)
        self.a.irq(trigger=Pin.IRQ_RISING | Pin.IRQ_FALLING, handler=self._cb)

    def _cb(self, pin):
        if self.a.value() == self.b.value():
            self.ticks += self.sign
        else:
            self.ticks -= self.sign

    def reset(self):
        self.ticks = 0

# ── Onboard LED ───────────────────────────────────────────────────────────────
led = Pin(25, Pin.OUT)
_led_ctr = 0

def heartbeat():
    global _led_ctr
    _led_ctr += 1
    if _led_ctr >= LOOP_HZ // 2:
        led.toggle()
        _led_ctr = 0

# ── Console print ─────────────────────────────────────────────────────────────
print_enabled = True
_print_ctr    = 0
PRINT_EVERY   = 10  # ~10 Hz

def maybe_print(angle, gyro_rate, output, vel, vel_offset, drive_offset, boost, turn):
    global _print_ctr
    if not print_enabled:
        return
    _print_ctr += 1
    if _print_ctr >= PRINT_EVERY:
        _print_ctr = 0
        print(f"tilt={angle:+6.2f}  out={output:+6.0f}  "
              f"vel={vel:+7.1f}  vsp={VEL_SETPOINT:+6.0f}  voff={vel_offset:+5.2f}  "
              f"doff={drive_offset:+5.2f}  boost={boost:.2f}  "
              f"L#={enc_left.ticks:+8d}  R#={enc_right.ticks:+8d}  "
              f"kick={kick_pwm:+6.0f}")

# ── MPU-6050 ──────────────────────────────────────────────────────────────────
MPU_ADDR = 0x68
i2c = I2C(0, sda=Pin(0), scl=Pin(1), freq=400_000)

def mpu_init():
    i2c.writeto_mem(MPU_ADDR, 0x6B, b'\x00')
    i2c.writeto_mem(MPU_ADDR, 0x1C, b'\x00')
    i2c.writeto_mem(MPU_ADDR, 0x1B, b'\x08')

IMU_OFF = {'gx': -109, 'gy': 337, 'gz': 25}

def read_raw():
    d = i2c.readfrom_mem(MPU_ADDR, 0x3B, 14)
    ax, ay, az, _, gx, gy, gz = struct.unpack('>hhhhhhh', d)
    return (ax, ay, az,
            gx - IMU_OFF['gx'],
            gy - IMU_OFF['gy'],
            gz - IMU_OFF['gz'])

# ── Complementary filter ──────────────────────────────────────────────────────
tilt_angle = 0.0
gyro_rate  = 0.0

def update_angle(ax, ay, az, gy):
    global tilt_angle, gyro_rate
    accel_angle = math.atan2(ay, az) * 57.2958
    gyro_rate   = gy / 65.5
    tilt_angle  = ALPHA * (tilt_angle + gyro_rate * DT) + (1 - ALPHA) * accel_angle
    return tilt_angle

# ── L298N with smooth deadband feedforward ───────────────────────────────────
def make_motor(pwm_pin, in1_pin, in2_pin):
    pwm = PWM(Pin(pwm_pin)); pwm.freq(20_000)
    in1 = Pin(in1_pin, Pin.OUT)
    in2 = Pin(in2_pin, Pin.OUT)
    return pwm, in1, in2

def drive(motor, speed):
    """Drive with smooth deadband compensation.

    The offset ramps in linearly between MIN_CMD and TRANSITION, so the
    motor PWM doesn't have an abrupt step at zero-crossing. Above
    TRANSITION the full MOTOR_OFFSET is applied.
    """
    pwm, in1, in2 = motor
    spd = int(speed)
    abs_spd = abs(spd)

    if abs_spd < MIN_CMD:
        in1.off(); in2.off(); pwm.duty_u16(0)
        return

    # Smooth ramp of the offset
    if abs_spd < TRANSITION:
        offset = MOTOR_OFFSET * (abs_spd / TRANSITION)
    else:
        offset = MOTOR_OFFSET

    actual = min(MAX_OUTPUT, abs_spd + int(offset))

    if spd > 0:
        in1.on();  in2.off(); pwm.duty_u16(actual)
    else:
        in1.off(); in2.on();  pwm.duty_u16(actual)

def stop_motors():
    drive(motor_l, 0)
    drive(motor_r, 0)

motor_l = make_motor(2, 3, 4)
motor_r = make_motor(5, 6, 7)

# ── Encoders ──────────────────────────────────────────────────────────────────
enc_left  = Encoder(12, 13, invert=True)
enc_right = Encoder(10, 11)

# ── UART1 (commands from Pi 4) ────────────────────────────────────────────────
_uart = UART(1, baudrate=115200, tx=Pin(8), rx=Pin(9))
_serial_buf = b''

# ── PID state ─────────────────────────────────────────────────────────────────
_d_buf = [0.0] * 5
_d_idx = 0
integral    = 0.0
prev_angle  = 0.0

def pid_step(angle, setpoint):
    global integral, prev_angle, _d_idx
    error = setpoint - angle

    if abs(error) < DEADBAND:
        prev_angle = angle
        return 0

    integral *= 0.91
    if abs(error) < INTEGRAL_ZONE:
        integral += error * DT
        integral  = max(-INTEGRAL_CLAMP, min(INTEGRAL_CLAMP, integral))
    else:
        integral = 0.0

    raw_d = (prev_angle - angle) / DT
    prev_angle = angle

    _d_buf[_d_idx] = raw_d
    _d_idx = (_d_idx + 1) % len(_d_buf)
    filtered_d = sum(_d_buf) / len(_d_buf)

    output = KP * error + KI * integral + KD * filtered_d
    return max(-MAX_OUTPUT, min(MAX_OUTPUT, output))

# ── Outer PID (velocity) ─────────────────────────────────────────────────────
vel_integral   = 0.0
vel_prev_error = 0.0
vel_filtered_d = 0.0
vel_offset     = 0.0
prev_ticks_l   = 0
prev_ticks_r   = 0
avg_velocity   = 0.0

def velocity_step():
    global vel_integral, vel_prev_error, vel_filtered_d, vel_offset
    global prev_ticks_l, prev_ticks_r, avg_velocity

    tl = enc_left.ticks
    tr = enc_right.ticks
    dt_vel = VEL_LOOP_DIV * DT

    vel_l = (tl - prev_ticks_l) / dt_vel
    vel_r = (tr - prev_ticks_r) / dt_vel
    avg_velocity = (vel_l + vel_r) / 2.0

    prev_ticks_l = tl
    prev_ticks_r = tr

    error = VEL_SETPOINT - avg_velocity

    vel_integral += error * dt_vel
    vel_integral  = max(-VEL_INTEGRAL_CLAMP / VEL_KI if VEL_KI > 0 else 0,
                        min( VEL_INTEGRAL_CLAMP / VEL_KI if VEL_KI > 0 else 0,
                             vel_integral))

    raw_d          = (error - vel_prev_error) / dt_vel
    vel_filtered_d = VEL_D_FILTER * raw_d + (1.0 - VEL_D_FILTER) * vel_filtered_d
    vel_prev_error = error

    offset = VEL_KP * error + VEL_KI * vel_integral + VEL_KD * vel_filtered_d
    vel_offset = max(-VEL_MAX_OFFSET, min(VEL_MAX_OFFSET, offset))

# ── Ramp helper ───────────────────────────────────────────────────────────────
def ramp_toward(current, target, rate, dt):
    max_step = rate * dt
    if current < target:
        return min(current + max_step, target)
    elif current > target:
        return max(current - max_step, target)
    return current

# ── Serial command parser ─────────────────────────────────────────────────────
killed              = False
drive_offset        = 0.0
drive_offset_target = 0.0
boost_val           = 0.0
turn_cmd            = 0.0
kick_pwm            = 0.0
prev_trigger_armed  = False

def parse_serial():
    global killed, _serial_buf, integral, prev_angle
    global vel_integral, vel_prev_error, vel_filtered_d, vel_offset
    global drive_offset, drive_offset_target, boost_val, turn_cmd
    global VEL_SETPOINT, VEL_SETPOINT_TARGET
    global kick_pwm, prev_trigger_armed

    if not _uart.any():
        return

    _serial_buf += _uart.read(_uart.any())

    while b'\n' in _serial_buf:
        line, _serial_buf = _serial_buf.split(b'\n', 1)
        line = line.strip().decode('utf-8', 'ignore')

        if line == 'K':
            killed              = True
            drive_offset        = 0.0
            drive_offset_target = 0.0
            boost_val           = 0.0
            turn_cmd            = 0.0
            VEL_SETPOINT        = 0.0
            VEL_SETPOINT_TARGET = 0.0
            integral            = 0.0
            vel_integral        = 0.0
            vel_offset          = 0.0
            vel_filtered_d      = 0.0
            kick_pwm            = 0.0
            prev_trigger_armed  = False
            stop_motors()
            print("CMD: KILL")

        elif line == 'R':
            killed              = False
            drive_offset        = 0.0
            drive_offset_target = 0.0
            boost_val           = 0.0
            turn_cmd            = 0.0
            VEL_SETPOINT        = 0.0
            VEL_SETPOINT_TARGET = 0.0
            integral            = 0.0
            prev_angle          = tilt_angle
            vel_integral        = 0.0
            vel_prev_error      = 0.0
            vel_filtered_d      = 0.0
            vel_offset          = 0.0
            kick_pwm            = 0.0
            prev_trigger_armed  = False
            enc_left.reset()
            enc_right.reset()
            print("CMD: RESUME")

        elif line == 'S':
            drive_offset_target = 0.0
            boost_val           = 0.0
            turn_cmd            = 0.0
            VEL_SETPOINT_TARGET = 0.0
            prev_trigger_armed  = False
            print("CMD: STOP")

        elif line.startswith('D'):
            try:
                rest = line[1:]
                d_str, rest2 = rest.split(',T')
                t_str, b_str = rest2.split(',B')
                joy_val      = float(d_str)
                boost_val    = float(b_str)
                turn_cmd     = float(t_str)

                drive_offset_target = joy_val  * MAX_DRIVE_ANGLE
                VEL_SETPOINT_TARGET = boost_val * VEL_DRIVE_SCALE

                trigger_armed = boost_val > TRIGGER_EDGE
                if trigger_armed and not prev_trigger_armed:
                    kick_pwm = KICK_PWM
                prev_trigger_armed = trigger_armed
            except Exception:
                print(f"CMD: parse error — '{line}'")

# ── Startup ───────────────────────────────────────────────────────────────────
time.sleep_ms(2000)
mpu_init()
time.sleep_ms(200)

print("Settling IMU...")
for _ in range(50):
    read_raw()
    time.sleep_ms(5)

prev_ticks_l = enc_left.ticks
prev_ticks_r = enc_right.ticks

print(f"CAMS Bot — smooth deadband (offset={MOTOR_OFFSET}, transition={TRANSITION})")
print(f"  KP={KP}  KD={KD}  SETPOINT={SETPOINT}°")
print("Send K to kill, R to resume")

# ── Main loop ─────────────────────────────────────────────────────────────────
next_tick = time.ticks_us()
interval  = int(DT * 1_000_000)
loop_ctr  = 0
_prev_output = 0.0
while True:
    now = time.ticks_us()
    if time.ticks_diff(now, next_tick) >= 0:
        next_tick = time.ticks_add(next_tick, interval)

        parse_serial()

        VEL_SETPOINT = ramp_toward(VEL_SETPOINT, VEL_SETPOINT_TARGET, VEL_RAMP_RATE,   DT)
        drive_offset = ramp_toward(drive_offset, drive_offset_target, DRIVE_RAMP_RATE, DT)

        kick_pwm *= KICK_DECAY
        if abs(kick_pwm) < KICK_MIN:
            kick_pwm = 0.0

        ax, ay, az, gx, gy, gz = read_raw()
        angle = update_angle(ax, ay, az, gy)

        if killed:
            stop_motors()
        else:
            loop_ctr += 1
            if loop_ctr >= VEL_LOOP_DIV:
                loop_ctr = 0
                velocity_step()

            effective_setpoint = SETPOINT + vel_offset + drive_offset
            output = pid_step(angle, effective_setpoint)
            _prev_output = OUTPUT_FILTER * output + (1.0 - OUTPUT_FILTER) * _prev_output

            turn_pwm = turn_cmd * TURN_SCALE
            drive(motor_l, _prev_output - turn_pwm + kick_pwm)
            drive(motor_r, _prev_output + turn_pwm + kick_pwm)

        maybe_print(angle, gyro_rate,
                    output if not killed else 0,
                    avg_velocity, vel_offset,
                    drive_offset, boost_val, turn_cmd)
        heartbeat()

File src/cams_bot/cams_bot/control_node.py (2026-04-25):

# # #!/usr/bin/env python3
# # """
# # CAMS Bot — Control Node
# # Reads /joy topic and sends drive/turn commands to Pico over USB serial.

# # Serial protocol:
# #   D<float>,T<float>\n  — set velocity target and turn offset
# #   S\n                  — stop: zero velocity and turn
# #   K\n                  — kill switch
# #   R\n                  — resume from kill

# # Xbox button mapping:
# #   B (index 1) — kill
# #   A (index 0) — resume

# # Launch:
# #   ros2 run cams_bot control_node
# # """

# # import rclpy
# # from rclpy.node import Node
# # from sensor_msgs.msg import Joy
# # import serial


# # # PICO_PORT = '/dev/ttyPICO'
# # PICO_PORT = '/dev/ttyAMA3'
# # BAUD_RATE = 115200

# # # Axis indices from joystick_node
# # AXIS_DRIVE = 1   # left stick Y  — forward/back
# # AXIS_TURN  = 3   # right stick X — left/right

# # # Button indices (Xbox controller)
# # BTN_KILL   = 1   # B button — kill
# # BTN_RESUME = 0   # A button — resume

# # # Scaling
# # MAX_DRIVE  = 1.0   # max joystick drive value sent to Pico (Pico scales by DRIVE_SCALE)
# # MAX_TURN   = 0.3   # max turn differential

# # DEADZONE   = 0.1

# # # Ramping
# # DRIVE_RAMP = 0.1
# # TURN_RAMP  = 0.05


# # class ControlNode(Node):
# #     def __init__(self):
# #         super().__init__('cams_bot_control_node')

# #         try:
# #             self.ser = serial.Serial(PICO_PORT, BAUD_RATE, timeout=1, write_timeout=0)
# #             self.get_logger().info(f'Connected to Pico on {PICO_PORT}')
# #         except serial.SerialException as e:
# #             self.get_logger().error(f'Failed to open {PICO_PORT}: {e}')
# #             raise

# #         self.killed    = False
# #         self.last_cmd  = None
# #         self.cur_drive = 0.0
# #         self.cur_turn  = 0.0
# #         self.raw_drive = 0.0
# #         self.raw_turn  = 0.0

# #         self.sub = self.create_subscription(Joy, 'joy', self.joy_callback, 10)
# #         self.timer = self.create_timer(0.05, self.timer_callback)  # 20 Hz
# #         self.get_logger().info('CAMS Bot control node ready')

# #     def joy_callback(self, msg: Joy):
# #         # ── Kill ──────────────────────────────────────────────────────────────
# #         if msg.buttons[BTN_KILL]:
# #             if not self.killed:
# #                 self.killed    = True
# #                 self.cur_drive = 0.0
# #                 self.cur_turn  = 0.0
# #                 self.raw_drive = 0.0
# #                 self.raw_turn  = 0.0
# #                 self.last_cmd  = None
# #                 self._send('K')
# #                 self.get_logger().warn('KILLED')
# #             return

# #         # ── Resume ────────────────────────────────────────────────────────────
# #         if msg.buttons[BTN_RESUME]:
# #             if self.killed:
# #                 self.killed    = False
# #                 self.cur_drive = 0.0
# #                 self.cur_turn  = 0.0
# #                 self.raw_drive = 0.0
# #                 self.raw_turn  = 0.0
# #                 self.last_cmd  = None
# #                 self._send('R')
# #                 self.get_logger().info('RESUMED')
# #             return

# #         if self.killed:
# #             return

# #         # ── Store raw joystick values ─────────────────────────────────────────
# #         raw_drive = -msg.axes[AXIS_DRIVE]
# #         raw_turn  =  msg.axes[AXIS_TURN]

# #         self.raw_drive = 0.0 if abs(raw_drive) < DEADZONE else raw_drive * MAX_DRIVE
# #         self.raw_turn  = 0.0 if abs(raw_turn)  < DEADZONE else raw_turn  * MAX_TURN

# #     def timer_callback(self):
# #         if self.killed:
# #             return

# #         self.cur_drive = self._ramp(self.cur_drive, self.raw_drive, DRIVE_RAMP)
# #         self.cur_turn  = self._ramp(self.cur_turn,  self.raw_turn,  TURN_RAMP)

# #         if self.cur_drive == 0.0 and self.cur_turn == 0.0:
# #             if self.last_cmd != 'S':
# #                 self.last_cmd = 'S'
# #                 self._send('S')
# #             return

# #         cmd = f'D{self.cur_drive:.3f},T{self.cur_turn:.3f}'
# #         if cmd != self.last_cmd:
# #             self.last_cmd = cmd
# #             self._send(cmd)
# #             self.get_logger().info(f'Sent: {cmd}')

# #     def _ramp(self, current, target, step):
# #         diff = target - current
# #         if abs(diff) <= step:
# #             return target
# #         return current + step * (1 if diff > 0 else -1)

# #     def _send(self, cmd: str):
# #         try:
# #             self.ser.write(f'{cmd}\n'.encode())
# #         except serial.SerialTimeoutException:
# #             pass  # drop the command, don't block
# #         except serial.SerialException as e:
# #             self.get_logger().error(f'Serial write failed: {e}')

# #     def destroy_node(self):
# #         self.get_logger().info('Shutting down — sending kill to Pico')
# #         self._send('K')
# #         self.ser.close()
# #         super().destroy_node()


# # def main(args=None):
# #     rclpy.init(args=args)
# #     try:
# #         node = ControlNode()
# #         rclpy.spin(node)
# #     except KeyboardInterrupt:
# #         pass
# #     finally:
# #         rclpy.shutdown()


# # if __name__ == '__main__':
# #     main()

# #!/usr/bin/env python3
# """
# CAMS Bot — Control Node
# Reads /joy topic and sends drive/turn/boost commands to Pico over UART.

# Serial protocol:
#   D<float>,T<float>,B<float>\n  — drive, turn, boost
#   S\n                           — stop: zero all
#   K\n                           — kill switch
#   R\n                           — resume from kill

# Xbox button mapping:
#   B (index 1) — kill
#   A (index 0) — resume

# Launch:
#   ros2 run cams_bot control_node
# """

# import rclpy
# from rclpy.node import Node
# from sensor_msgs.msg import Joy
# import serial


# PICO_PORT = '/dev/ttyAMA3'
# BAUD_RATE = 115200

# # Axis indices
# AXIS_DRIVE = 1   # left stick Y  — forward/back
# AXIS_TURN  = 0   # left stick X  — left/right
# AXIS_BOOST = 5   # right trigger — speed boost

# # Button indices (Xbox controller)
# BTN_KILL   = 1   # B button — kill
# BTN_RESUME = 0   # A button — resume

# # Scaling
# MAX_DRIVE  = 1.0   # max joystick drive value sent to Pico
# MAX_TURN   = 0.3   # max turn differential

# DEADZONE   = 0.1

# # Ramping
# DRIVE_RAMP = 0.1
# TURN_RAMP  = 0.05


# class ControlNode(Node):
#     def __init__(self):
#         super().__init__('cams_bot_control_node')

#         try:
#             self.ser = serial.Serial(PICO_PORT, BAUD_RATE, timeout=1, write_timeout=0)
#             self.get_logger().info(f'Connected to Pico on {PICO_PORT}')
#         except serial.SerialException as e:
#             self.get_logger().error(f'Failed to open {PICO_PORT}: {e}')
#             raise
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
